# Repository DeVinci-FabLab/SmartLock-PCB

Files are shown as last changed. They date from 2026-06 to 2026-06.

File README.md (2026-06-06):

# SmartLock-PCB

\# SmartLock-PCB

PCB design for the SmartLock project — an electronically controlled lock system developed at the DeVinci FabLab.

Designed with \*\*KiCad\*\*.

\---

\## Project Structure

SmartLock-PCB/

├── SmartLock.kicad\_pro       # KiCad project file

├── SmartLock.kicad\_sch       # Schematic

├── SmartLock.kicad\_pcb       # PCB layout

├── gerbers/                  # Fabrication files (Gerber + drill)

├── bom/                      # Bill of Materials

└── README.md

\## Description

This board handles the control logic for the SmartLock system. It interfaces with:

\- An electronic locking mechanism (solenoid / servo)

\- An access control module (badge reader / keypad / BLE)

\- A microcontroller for logic and communication

>  This section should be updated with the actual components once the schematic is finalized.

\---

\## How to Open the Project

1\. Install \[KiCad](https://www.kicad.org/) (version 7 or later recommended)

2\. Clone this repository:

```

&#x20;  git clone https://github.com/DeVinci-FabLab/SmartLock-PCB.git

```

3\. Open `SmartLock.kicad\_pro` in KiCad

\---

\## Ordering the PCB

Gerber files for fabrication are located in the `gerbers/` folder.  

They can be sent directly to a PCB manufacturer (JLCPCB, PCBWay, etc.).

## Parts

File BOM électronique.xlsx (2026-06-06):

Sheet: Feuil1
Numéro d'article | Article | Type/Catégorie | Quantité | Fournisseur | Coût Unitaire | Coût Total Estimé | Lien
1 | Rasp 0 12W (Raspberry Pi) | Micro-ordinateur U10 | 3 | Kubii | 18.00 € | 54.00 € | https://www.kubii.com/fr/cartes-nano-ordinateurs/3455-raspberry-pi-zero-2-w.html?src=raspberrypi
2 | BIGTREETECH SKSM V1.0 | Carte sauveuse de donnée J2 | 3 | Biqu | 16.25 € | 48.75 € | https://biqu.equipment/products/bigtreetech-sksm-v1-0
3 | PN532 | Lecteur RFID/NFC U20 | 3 | robotshop | 5.94 € | 17.82 € | https://eu.robotshop.com/products/elecrow-pn532-nfc-module-pn532-rfid-v3-module
4 | 7inch Capacitive Touch Screen LCD (H), 1024×600, HDMI, IPS, Various Systems Support | Écran / IHM | 3 | Gotronic | 47.99 € | 143.97 € | https://www.waveshare.com/7inch-hdmi-lcd-h.htm
5 | Capteur a effet hall | Capteur magnétique U15 | 3 | RS | 2.05 € | 6.15 € | https://fr.rs-online.com/web/p/capteurs-a-effet-hall/1811441
6 | Led rouge | Composants elec D20, D21 | 6 | Gotronic | 0.90 € | 5.40 € | https://www.gotronic.fr/art-led-5-mm-l56bhd-2104.htm
7 | Buzzer | Composants elec BZ2 | 3 | Gotronic | 3.60 € | 10.80 € | https://www.gotronic.fr/art-buzzer-sv4-3830.htm
8 | Samsung 25R 18650 | Batterie de secours BT4, BT5, BT6 | 9 | Taklope | 4.30 € | 38.70 € | https://www.taklope.com/samsung/2240-samsung-inr-25r-18650-2500-mah.html
9 | Régulateur CC-CC MC34063ADR | Step-up / Step-down U1-U4 | 25 | RS | 0.57 € | 14.27 € | https://fr.rs-online.com/web/p/convertisseurs-dc-dc/2184547
10 | Interupteur | Protection de circuit SW1 | 3 | RS | 4.50 € | 13.50 € | https://fr.rs-online.com/web/p/interrupteurs-a-bascule/1858229
11 | Solénoïde | Verrou L10 | 3 | JZIK (sinon amazon) | 7.76 € | 23.28 € | https://www.jzk-jzk.com/fr/products/dc-12v-electric-solenoid-lock-assembly-security-lock-for-security-system-safes-door-cabinet
12 | Porte-fusible PF14 | Protection de circuit | 3 | Gotronic | 0.25 € | 0.75 € | https://www.gotronic.fr/art-porte-fusible-pf14-5553.htm
13 | Fusible temporisé 3,15 A | Protection de circuit F1 | 6 | Gotronic | 0.25 € | 1.50 € | https://www.gotronic.fr/art-fusible-temporise-3-15-a-5485.htm
14 | Diode 1N5822 | D1-D4, D10, D11 | 20 | Gotronic | 0.50 € | 10.00 € | https://www.gotronic.fr/art-1n5822-105.htm
15 | Adaptateur AC/DC 220V-12V | Alimentation secteur J8 | 3 | RS | 25.98 € | 77.94 € | https://fr.rs-online.com/web/p/adaptateurs-ac-dc/1753327
16 | Connecteur Aviateur | Connectique J3, J9 | 3 | Audiophonics | 1.90 € | 5.70 € | https://www.audiophonics.fr/en/plane-type-plugs/gx12-connector-2-poles-300v-5a-o5mm-p-9979.html
17 | Mosfet | Connectique Q1 | 3 | RS | 1.28 € | 3.84 € | https://fr.rs-online.com/web/p/transistors-mosfet/5410086 | Total 3 armoires | 544.76 €
18 | Cable Hdmi - mini Hdmi | Câblage | 3 | RS | 10.25 € | 30.75 € | https://fr.rs-online.com/web/p/cables-hdmi/1828892 | Total 1 armoire | 181.59 €
19 | BMS 3S | Gestion batterie J10 | 3 | Otronic | 2.05 € | 6.15 € | https://www.otronic.nl/fr/circuit-de-protection-bms-3s-avec-fonction-dequili.html
20 | Cable Usb - Micro Usb | Câblage | 3 | Gotronic | 3.90 € | 11.70 € | https://www.gotronic.fr/art-cordon-micro-usb-32141.htm
21 | Inductance 100µH | L1, L2, L3 | 3 | Gotronic | 0.60 € | 1.80 € | https://www.gotronic.fr/art-self-miniature-100-uh-3521.htm
22 | Inductance 150µH | L4 | 1 | Switch eletronics | 1.78 € | 1.78 € | https://www.switchelectronics.co.uk/products/150%C2%B5h-10-radial-inductor-22r154c
23 | R 13 kΩ | R32 | 5 | e44 | 0.10 € | 0.50 € | https://www.e44.com/composants/composants-passifs/resistances/resistances-precision/0-25-w/resistance-couche-metallique-1-4w-13-kohms-1-MA13K0.html
24 | R 1.5 Ω | R_SC4 | 1 | Gotronic | 0.15 € | 0.15 € | https://www.gotronic.fr/art-10-resistances-1-4w-1-5-8486-2545.htm
25 | R 3.6 kΩ | R12, R22 | 2 | RS | 4.28 € | 8.56 € | https://ma.rsdelivers.com/product/vishay/mrs25000c3601fct00/resistance-film-couche-mince-36k%CF%89-1-06w/6834219P
26 | R 9.1 kΩ | R42 | 1 | Gotronic | 0.25 € | 0.25 € | https://www.gotronic.fr/art-5-resistances-1-2w-9-1-k-8486-8835.htm
27 | R 1.0 kΩ | R41 | 1 | Gotronic | 0.15 € | 0.15 € | https://www.gotronic.fr/art-10-resistances-1-4w-1-0k-8486-2574.htm
28 | R 1.2 kΩ | R11, R21 | 1 | Gotronic | 0.15 € | 0.15 € | https://www.gotronic.fr/art-10-resistances-1-4w-1-2k-8486-2575.htm
29 | R 0.33 Ω | R_SC1, R_SC2 | 2 | Gotronic | 0.55 € | 1.10 € | https://www.gotronic.fr/art-resistance-bobinee-5w-0-33-8486-2813.htm
30 | R 0.47 Ω | R_SC3 | 2 | Gotronic | 0.55 € | 1.10 € | https://www.gotronic.fr/art-resistance-bobinee-5w-0-47-8486-2815.htm
31 | R 1.5 kΩ | R31 | 1 | Gotronic | 0.15 € | 0.15 € | https://www.gotronic.fr/art-10-resistances-1-4w-1-5k-8486-2576.htm
32 | C 560 pF | C_T1 | 1 | Gotronic | 0.10 € | 0.10 € | https://www.gotronic.fr/art-condensateur-ceramique-560-pf-3195.htm
33 | C 100µF/50V | C1, C_O1, C2, C3, C_O3, C4, C_O4 | 15 | Gotronic | 0.20 € | 3.00 € | https://www.gotronic.fr/art-condensateur-radial-100uf-50v-229.htm
34 | C 680 pF | C_T2 | 1 | Gotronic | 0.10 € | 0.10 € | https://www.gotronic.fr/art-condensateur-ceramique-680-pf-3196.htm
35 | C 220 µF / 50V | C_O2 | 5 | Gotronic | 0.10 € | 0.50 € | https://www.gotronic.fr/art-condensateur-radial-220uf-50v-3381.htm
36 | C 150 pF | C_T3 | 1 | Gotronic | 0.10 € | 0.10 € | https://www.gotronic.fr/art-condensateur-ceramique-150-pf-3188.htm
37 | C 120 pF | C_T4 | 1 | Gotronic | 0.10 € | 0.10 € | https://www.gotronic.fr/art-condensateur-ceramique-120-pf-3187.htm
38 | R 330 Ω | R1, R2, R3, R4 | 1 | Gotronic | 0.20 € | 0.20 € | https://www.gotronic.fr/art-10-resistances-1-4w-330-8486-2570.htm
 |  |  |  |  |  | 0.00 €
 | R 1.5 kΩ | R11
 | R 4,7 kΩ | R12
 | R 0.15 Ω | R_SC1

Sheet: Feuil2
Régulateur 12V-5V (page 9) |  |  |  |  | Condensateurs |  |  | Résistances |  |  | Inductances |  |  | Diodes
Composant | Valeur Calculée | Valeur Suggérée (E12/E24) |  |  | 560.00 | pF (céramique) | 2 | 0.33 | Ω | 3 | 100 | µH | 4 | 1N5819 | Schottky
CT (C1) | 564 pF | 560 pF (Céramique) |  | 8 | 100 | µF (chimique 15-25V) | 2 | 1200 | Ω |  | 150 | µH
Rsc (R3) | 0,3 Ω | 0,33 Ω (1/2W) |  |  | 680 | pF | 2 | 3600 | Ω
L (L1) | 87,4μH | 100μH (Courant >1,2 A) |  |  | 220 | µF |  | 1500 | Ω
Co (C2) | 75μF | 100μF (Chimique, 16V ou 25V) |  |  | 150 | pF |  | 13000 | Ω
R1 | 1,2 kΩ | 1,2 kΩ |  |  | 120 | pF |  | 0.47 | Ω
R2 | 3,6 kΩ | 3,6 kΩ |  |  |  |  |  | 1000 | Ω
D1 | Diode Schottky | 1N5819 |  |  |  |  |  | 9100 | Ω
 |  |  |  |  |  |  |  | 1.5 | Ω
Régulateur 11,1V-5V (page 10)
Composant | Valeur Calculée | Valeur Standard (Marché) | Rôle
R1 | 1.2kΩ | 1.2kΩ | Pont diviseur
R2 | 3.6kΩ | 3.6kΩ | Fixe la tension à 5.0V
Rsc | 0.3Ω | 0.33Ω (1W) | Limite le courant pic (~0.9A)
Ct | 620pF | 680pF | Condensateur de timing
L1 | 78μH | 100μH | Inductance (Courant > 1A)
Co | 110μF | 220μF | Condensateur sortie (Low ESR)
D1 | Schottky | 1N5819 | Diode de roue libre
Régulateur 11,1V-12V (page 11)
Composant | Valeur Calculée | Valeur Standard (Marché) | Rôle
R1 | 1.5kΩ | 1.5kΩ | Pont diviseur
R2 | 12.9kΩ | 13kΩ | Fixe la tension à ~12.08V
Ct | 140pF | 150pF | Critique : Valeur très faible due au rapport cyclique court.
L1 | 82μH | 100μH | Inductance (Courant > 0.5A)
Rsc | 0.66Ω | 0.47Ω ou 0.5Ω | Limite de courant (~0.6A pic)
Co | 10μF (min) | 100μF | Électrolytique (25V)
D1 | Schottky | 1N5819 | Diode rapide
Régulateur 12V-12,6V (page 12)
Composant | Valeur Calculée | Valeur Standard Recommandée | Note Technique
R1 | 1kΩ | 1kΩ
R2 | 9.08kΩ | 9.1kΩ | Donne Vout≈12.62V
Ct | 120pF | 100pF ou 120pF | Attention : Valeur très faible car le temps d'activation (ton) est court.
L1 | 145μH | 150μH | Pour Iout=100mA
Rsc | 1.36Ω | 1.2Ω ou 1.5Ω | Limite le courant pic (Ipk) à ~250mA pour protéger la charge.
Co | 10μF (min) | 100μF | Électrolytique (Low ESR)

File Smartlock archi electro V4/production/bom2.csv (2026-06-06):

Id | Référence | Empreinte | Quantité | Désignation | Fournisseur et réf
1 | U?,U? | CONN-TH_XH-2A | 2 | CONN-TH_XH-2A
2 | U? | CONN-TH_4P-P2.50_XH-4A | 1 | CONN-TH_4P-P2.50_XH-4A
3 | R31,R32,R22,R21,R12,R11,R3,R2,R1 | R0805 | 9 | R
4 | D3,D12,D11,D10,D4,D2,D1 | SMA_L4.3-W2.6-LS5.2-RD | 7 | 1N5822
5 | U? | CONN-TH_XH-3A | 1 | CONN-TH_XH-3A
6 | R42 | R0402 | 1 | R
7 | C_O4,C_O3,C_O1,C4,C3,C2,C1 | CAP-SMD_BD8.0-L8.3-W8.3-LS9.1-FD | 7 | C_Polarized
8 | U? | CONN-TH_5P-P2.50_XH-5A_C2318 | 1 | CONN-TH_5P-P2.50_XH-5A_C2318
9 | U4 | SOIC-8_L4.9-W3.9-P1.27-LS6.0-BL | 1 | Regulator 12V-12.6V
10 | U3 | SOIC-8_L4.9-W3.9-P1.27-LS6.0-BL | 1 | Regulator 11.1V-12V
11 | U2 | SOIC-8_L4.9-W3.9-P1.27-LS6.0-BL | 1 | Regulator 11.1V-5V
12 | U1 | SOIC-8_L4.9-W3.9-P1.27-LS6.0-BL | 1 | Regulator 12V-5V
13 | R_SC4,R_SC2,R_SC1,R_PD1,R41 | R1206 | 5 | R
14 | R_SC3 | R0603 | 1 | R
15 | R40 | R1206 | 1 | R40
16 | R30 | R1206 | 1 | R30
17 | Q1 | SOT-23-3_L2.9-W1.3-P1.90-LS2.4-BR | 1 | Q_NMOS_GSD
18 | L4 | IND-SMD_L12.3-W12.3 | 1 | L4
19 | L3 | IND-SMD_L12.3-W12.3_SMDRI127 | 1 | L3
20 | L2 | IND-SMD_L12.3-W12.3_SMDRI127 | 1 | L2
21 | L1 | IND-SMD_L12.3-W12.3_SMDRI127 | 1 | L1
22 | C_T4,C_T3,C_T2,C_T1 | C0603 | 4 | C
23 | C_O2 | CAP-SMD_BD10.0-L10.3-W10.3-LS11.3-FD | 1 | C_Polarized

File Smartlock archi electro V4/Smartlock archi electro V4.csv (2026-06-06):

Reference | Qty | Value | DNP | Exclude from BOM | Exclude from Board | Footprint | JLCPCB
BT4 | 1 | Battery
BT5 | 1 | Battery
BT6 | 1 | Battery
BZ2 | 1 | Buzzer
C1 | 1 | C_Polarized |  |  |  | Components_local:CAP-SMD_BD8.0-L8.3-W8.3-LS9.1-FD | https://jlcpcb.com/partdetail/DMBJ-RVT1H101M0810_100UF50V/C970687
C2 | 1 | C_Polarized |  |  |  | Components_local:CAP-SMD_BD8.0-L8.3-W8.3-LS9.1-FD | https://jlcpcb.com/partdetail/DMBJ-RVT1H101M0810_100UF50V/C970687
C3 | 1 | C_Polarized |  |  |  | Components_local:CAP-SMD_BD8.0-L8.3-W8.3-LS9.1-FD | https://jlcpcb.com/partdetail/DMBJ-RVT1H101M0810_100UF50V/C970687
C4 | 1 | C_Polarized |  |  |  | Components_local:CAP-SMD_BD8.0-L8.3-W8.3-LS9.1-FD | https://jlcpcb.com/partdetail/DMBJ-RVT1H101M0810_100UF50V/C970687
C_O1 | 1 | C_Polarized |  |  |  | Components_local:CAP-SMD_BD8.0-L8.3-W8.3-LS9.1-FD | https://jlcpcb.com/partdetail/DMBJ-RVT1H101M0810_100UF50V/C970687
C_O2 | 1 | C_Polarized |  |  |  | Components_local:CAP-SMD_BD10.0-L10.3-W10.3-LS11.3-FD | https://jlcpcb.com/partdetail/DMBJ-RVT1H221M1010_220UF50V/C970698
C_O3 | 1 | C_Polarized |  |  |  | Components_local:CAP-SMD_BD8.0-L8.3-W8.3-LS9.1-FD | https://jlcpcb.com/partdetail/DMBJ-RVT1H101M0810_100UF50V/C970687
C_O4 | 1 | C_Polarized |  |  |  | Components_local:CAP-SMD_BD8.0-L8.3-W8.3-LS9.1-FD | https://jlcpcb.com/partdetail/DMBJ-RVT1H101M0810_100UF50V/C970687
C_T1 | 1 | C |  |  |  | Components_local:C0603 | https://jlcpcb.com/partdetail/1979-0603B561K500NT/C1627
C_T2 | 1 | C |  |  |  | Components_local:C0603 | https://jlcpcb.com/partdetail/1982-0603B681K500NT/C1630
C_T3 | 1 | C |  |  |  | Components_local:C0603 | https://jlcpcb.com/partdetail/1946-0603B151K500NT/C1594
C_T4 | 1 | C |  |  |  | Components_local:C0603 | https://jlcpcb.com/partdetail/1995-0603CG121J500NT/C1643
D1 | 1 | 1N5822 |  |  |  | Components_local:SMA_L4.3-W2.6-LS5.2-RD | https://jlcpcb.com/partdetail/MDD_Microdiode_Semiconductor-SS34/C8678
D2 | 1 | 1N5822 |  |  |  | Components_local:SMA_L4.3-W2.6-LS5.2-RD | https://jlcpcb.com/partdetail/MDD_Microdiode_Semiconductor-SS34/C8678
D3 | 1 | 1N5822 |  |  |  | Components_local:SMA_L4.3-W2.6-LS5.2-RD | https://jlcpcb.com/partdetail/MDD_Microdiode_Semiconductor-SS34/C8678
D4 | 1 | 1N5822 |  |  |  | Components_local:SMA_L4.3-W2.6-LS5.2-RD | https://jlcpcb.com/partdetail/MDD_Microdiode_Semiconductor-SS34/C8678
D10 | 1 | 1N5822 |  |  |  | Components_local:SMA_L4.3-W2.6-LS5.2-RD | https://jlcpcb.com/partdetail/MDD_Microdiode_Semiconductor-SS34/C8678
D11 | 1 | 1N5822 |  |  |  | Components_local:SMA_L4.3-W2.6-LS5.2-RD | https://jlcpcb.com/partdetail/MDD_Microdiode_Semiconductor-SS34/C8678
D12 | 1 | 1N5822 |  |  |  | Components_local:SMA_L4.3-W2.6-LS5.2-RD | https://jlcpcb.com/partdetail/MDD_Microdiode_Semiconductor-SS34/C8678
D20 | 1 | LED
D21 | 1 | LED
F1 | 1 | Fuse
J1 | 1 | HDMI_A
J2 | 1 | SKSM V1.0
J3 | 1 | Conn_aviateur in
J4 | 1 | HDMI_C_1.3
J5 | 1 | USB_OTG
J6 | 1 | USB_A
J7 | 1 | USB_OTG
J8 | 1 | Adaptateur 220V-12V
J9 | 1 | Conn_aviateur out
J10 | 1 | BMS_3S
L1 | 1 | L1 |  |  |  | Components_local:IND-SMD_L12.3-W12.3_SMDRI127 | https://jlcpcb.com/partdetail/10690-SMDRI127101MT/C10150
L2 | 1 | L2 |  |  |  | Components_local:IND-SMD_L12.3-W12.3_SMDRI127 | https://jlcpcb.com/partdetail/10690-SMDRI127101MT/C10150
L3 | 1 | L3 |  |  |  | Components_local:IND-SMD_L12.3-W12.3_SMDRI127 | https://jlcpcb.com/partdetail/10690-SMDRI127101MT/C10150
L4 | 1 | L4 |  |  |  | Components_local:IND-SMD_L12.3-W12.3 | https://jlcpcb.com/partdetail/22042-SMDRI127151MT/C21325
L10 | 1 | Solénoïde
Q1 | 1 | Q_NMOS_GSD |  |  |  | Components_local:SOT-23-3_L2.9-W1.3-P1.90-LS2.4-BR | https://jlcpcb.com/partdetail/Alpha_OmegaSemicon-AO3400A/C20917
R1 | 1 | R |  |  |  | Components_local:R0805 | https://jlcpcb.com/partdetail/18318-0805W8F3300T5E/C17630
R2 | 1 | R |  |  |  | Components_local:R0805 | https://jlcpcb.com/partdetail/18318-0805W8F3300T5E/C17630
R3 | 1 | R |  |  |  | Components_local:R0805 | https://jlcpcb.com/partdetail/18318-0805W8F3300T5E/C17630
R4 | 1 | R |  |  |  | Components_local:R0805
R11 | 1 | R |  |  |  | Components_local:R0805 | https://jlcpcb.com/partdetail/18067-0805W8F1201T5E/C17379
R12 | 1 | R |  |  |  | Components_local:R0805 | https://jlcpcb.com/partdetail/1717-0805W8J0362T5E/C1365
R21 | 1 | R |  |  |  | Components_local:R0805 | https://jlcpcb.com/partdetail/18067-0805W8F1201T5E/C17379
R22 | 1 | R |  |  |  | Components_local:R0805 | https://jlcpcb.com/partdetail/1717-0805W8J0362T5E/C1365
R30 | 1 | R30 |  |  |  | Components_local:R1206 | https://jlcpcb.com/partdetail/18612-1206W4F1800T5E/C17924
R31 | 1 | R |  |  |  | Components_local:R0805 | https://jlcpcb.com/partdetail/4717-0805W8F1501T5E/C4310
R32 | 1 | R |  |  |  | Components_local:R0805 | https://jlcpcb.com/partdetail/18143-0805W8F1302T5E/C17455
R40 | 1 | R40 |  |  |  | Components_local:R1206 | https://jlcpcb.com/partdetail/18612-1206W4F1800T5E/C17924
R41 | 1 | R |  |  |  | Components_local:R1206 | https://jlcpcb.com/partdetail/1821-1206W4J0102T5E/C1469
R42 | 1 | R |  |  |  | Capacitor_SMD_local:R0603 | https://jlcpcb.com/partdetail/VikingTech-ARG03BTC8761N/C2684583
R_PD1 | 1 | R |  |  |  | Components_local:R1206 | https://jlcpcb.com/partdetail/1841-1206W4J0103T5E/C1489
R_SC1 | 1 | R |  |  |  | Components_local:R1206 | https://jlcpcb.com/partdetail/26080-1206W4F330LT5E/C25337
R_SC2 | 1 | R |  |  |  | Components_local:R1206 | https://jlcpcb.com/partdetail/26080-1206W4F330LT5E/C25337
R_SC3 | 1 | R |  |  |  | Components_local:R0603 | https://jlcpcb.com/partdetail/24144-0603WAF470LT5E/C23411
R_SC4 | 1 | R |  |  |  | Components_local:R1206 | https://jlcpcb.com/partdetail/18587-1206W4F150KT5E/C17899
SW1 | 1 | Interupteur
U1 | 1 | Regulator 12V-5V |  |  |  | Components_local:SOIC-8_L4.9-W3.9-P1.27-LS6.0-BL | https://jlcpcb.com/partdetail/TexasInstruments-MC34063ADR/C100023
U2 | 1 | Regulator 11.1V-5V |  |  |  | Components_local:SOIC-8_L4.9-W3.9-P1.27-LS6.0-BL | https://jlcpcb.com/partdetail/TexasInstruments-MC34063ADR/C100023
U3 | 1 | Regulator 11.1V-12V |  |  |  | Components_local:SOIC-8_L4.9-W3.9-P1.27-LS6.0-BL | https://jlcpcb.com/partdetail/TexasInstruments-MC34063ADR/C100023
U4 | 1 | Regulator 12V-12.6V |  |  |  | Components_local:SOIC-8_L4.9-W3.9-P1.27-LS6.0-BL | https://jlcpcb.com/partdetail/TexasInstruments-MC34063ADR/C100023
U5 | 1 | LTV-817 |  |  |  | Components_local:OPTO-SMD-4_L4.6-W6.5-P2.54-LS10.3-BL | https://jlcpcb.com/parts/componentSearch?searchTxt=817%20SOP-4
U10 | 1 | RASPBERRY_PI_ZERO_2_W
U15 | 1 | Capteur magnetic
U20 | 1 | PN532

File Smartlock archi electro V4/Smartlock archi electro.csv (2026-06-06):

Reference | Qty | Value | DNP | Exclude from BOM | Exclude from Board | Footprint | JLCPCB
BT4,BT5,BT6 | 3 | Battery
BZ2 | 1 | Buzzer
C1,C2,C3,C4 | 4 | C_Polarized |  |  |  | Components_local:CAP-SMD_BD8.0-L8.3-W8.3-LS9.1-FD | https://jlcpcb.com/partdetail/DMBJ-RVT1H101M0810_100UF50V/C970687,https://jlcpcb.com/partdetail/DMBJ-RVT1H101M0810_100UF50V/C970687
C_O1,C_O3,C_O4 | 3 | C_Polarized |  |  |  | Components_local:CAP-SMD_BD8.0-L8.3-W8.3-LS9.1-FD | https://jlcpcb.com/partdetail/DMBJ-RVT1H101M0810_100UF50V/C970687
C_O2 | 1 | C_Polarized |  |  |  | Components_local:CAP-SMD_BD10.0-L10.3-W10.3-LS11.3-FD | https://jlcpcb.com/partdetail/DMBJ-RVT1H221M1010_220UF50V/C970698
C_T1,C_T2,C_T3,C_T4 | 4 | C |  |  |  | Components_local:C0603 | https://jlcpcb.com/partdetail/1946-0603B151K500NT/C1594,https://jlcpcb.com/partdetail/1979-0603B561K500NT/C1627 ,https://jlcpcb.com/partdetail/1982-0603B681K500NT/C1630 ,https://jlcpcb.com/partdetail/1995-0603CG121J500NT/C1643
D1,D2,D3,D4,D10,D11,D12 | 7 | 1N5822 |  |  |  | Components_local:SMA_L4.3-W2.6-LS5.2-RD | https://jlcpcb.com/partdetail/MDD_Microdiode_Semiconductor-SS34/C8678
D20,D21 | 2 | LED
F1 | 1 | Fuse
J1 | 1 | HDMI_A
J2 | 1 | SKSM V1.0
J3 | 1 | Conn_aviateur in
J4 | 1 | HDMI_C_1.3
J5,J7 | 2 | USB_OTG
J6 | 1 | USB_A
J8 | 1 | Adaptateur 220V-12V
J9 | 1 | Conn_aviateur out
J10 | 1 | BMS_3S
L1 | 1 | L1 |  |  |  | Components_local:IND-SMD_L12.3-W12.3_SMDRI127 | https://jlcpcb.com/partdetail/10690-SMDRI127101MT/C10150
L2 | 1 | L2 |  |  |  | Components_local:IND-SMD_L12.3-W12.3_SMDRI127 | https://jlcpcb.com/partdetail/10690-SMDRI127101MT/C10150
L3 | 1 | L3 |  |  |  | Components_local:IND-SMD_L12.3-W12.3_SMDRI127 | https://jlcpcb.com/partdetail/10690-SMDRI127101MT/C10150
L4 | 1 | L4 |  |  |  | Components_local:IND-SMD_L12.3-W12.3 | https://jlcpcb.com/partdetail/22042-SMDRI127151MT/C21325
L10 | 1 | Solénoïde
Q1 | 1 | Q_NMOS_GSD |  |  |  | Components_local:SOT-23-3_L2.9-W1.3-P1.90-LS2.4-BR | https://jlcpcb.com/partdetail/Alpha_OmegaSemicon-AO3400A/C20917
R1,R2,R3,R11,R12,R21,R22,R31,R32 | 9 | R |  |  |  | Components_local:R0805 | https://jlcpcb.com/partdetail/1717-0805W8J0362T5E/C1365 ,https://jlcpcb.com/partdetail/18067-0805W8F1201T5E/C17379 ,https://jlcpcb.com/partdetail/18143-0805W8F1302T5E/C17455 ,https://jlcpcb.com/partdetail/18318-0805W8F3300T5E/C17630 ,https://jlcpcb.com/partdetail/4717-0805W8F1501T5E/C4310
R30 | 1 | R30 |  |  |  | Components_local:R1206 | https://jlcpcb.com/partdetail/18612-1206W4F1800T5E/C17924
R40 | 1 | R40 |  |  |  | Components_local:R1206 | https://jlcpcb.com/partdetail/18612-1206W4F1800T5E/C17924
R41 | 1 | R |  |  |  | Components_local:R1206 | https://jlcpcb.com/partdetail/1821-1206W4J0102T5E/C1469
R42 | 1 | R |  |  |  | Components_local:R0402 | https://jlcpcb.com/partdetail/RALEC-RTT029101FTH/C4968
R_PD1 | 1 | R |  |  |  | Components_local:R1206 | https://jlcpcb.com/partdetail/1841-1206W4J0103T5E/C1489
R_SC1,R_SC2,R_SC4 | 3 | R |  |  |  | Components_local:R1206 | https://jlcpcb.com/partdetail/18587-1206W4F150KT5E/C17899 ,https://jlcpcb.com/partdetail/26080-1206W4F330LT5E/C25337
R_SC3 | 1 | R |  |  |  | Components_local:R0603 | https://jlcpcb.com/partdetail/24144-0603WAF470LT5E/C23411
SW1 | 1 | Interupteur
U1 | 1 | Regulator 12V-5V |  |  |  | Components_local:SOIC-8_L4.9-W3.9-P1.27-LS6.0-BL | https://jlcpcb.com/partdetail/TexasInstruments-MC34063ADR/C100023
U2 | 1 | Regulator 11.1V-5V |  |  |  | Components_local:SOIC-8_L4.9-W3.9-P1.27-LS6.0-BL | https://jlcpcb.com/partdetail/TexasInstruments-MC34063ADR/C100023
U3 | 1 | Regulator 11.1V-12V |  |  |  | Components_local:SOIC-8_L4.9-W3.9-P1.27-LS6.0-BL | https://jlcpcb.com/partdetail/TexasInstruments-MC34063ADR/C100023
U4 | 1 | Regulator 12V-12.6V |  |  |  | Components_local:SOIC-8_L4.9-W3.9-P1.27-LS6.0-BL | https://jlcpcb.com/partdetail/TexasInstruments-MC34063ADR/C100023
U10 | 1 | RASPBERRY_PI_ZERO_2_W
U15 | 1 | Capteur magnetic
U20 | 1 | PN532

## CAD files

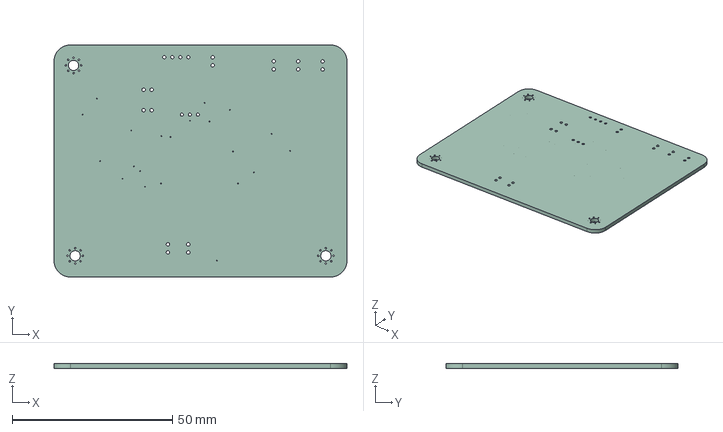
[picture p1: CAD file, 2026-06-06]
Smartlock archi electro V4/Smartlock archi electro V4.step
91.4 x 72.4 x 1.51 mm

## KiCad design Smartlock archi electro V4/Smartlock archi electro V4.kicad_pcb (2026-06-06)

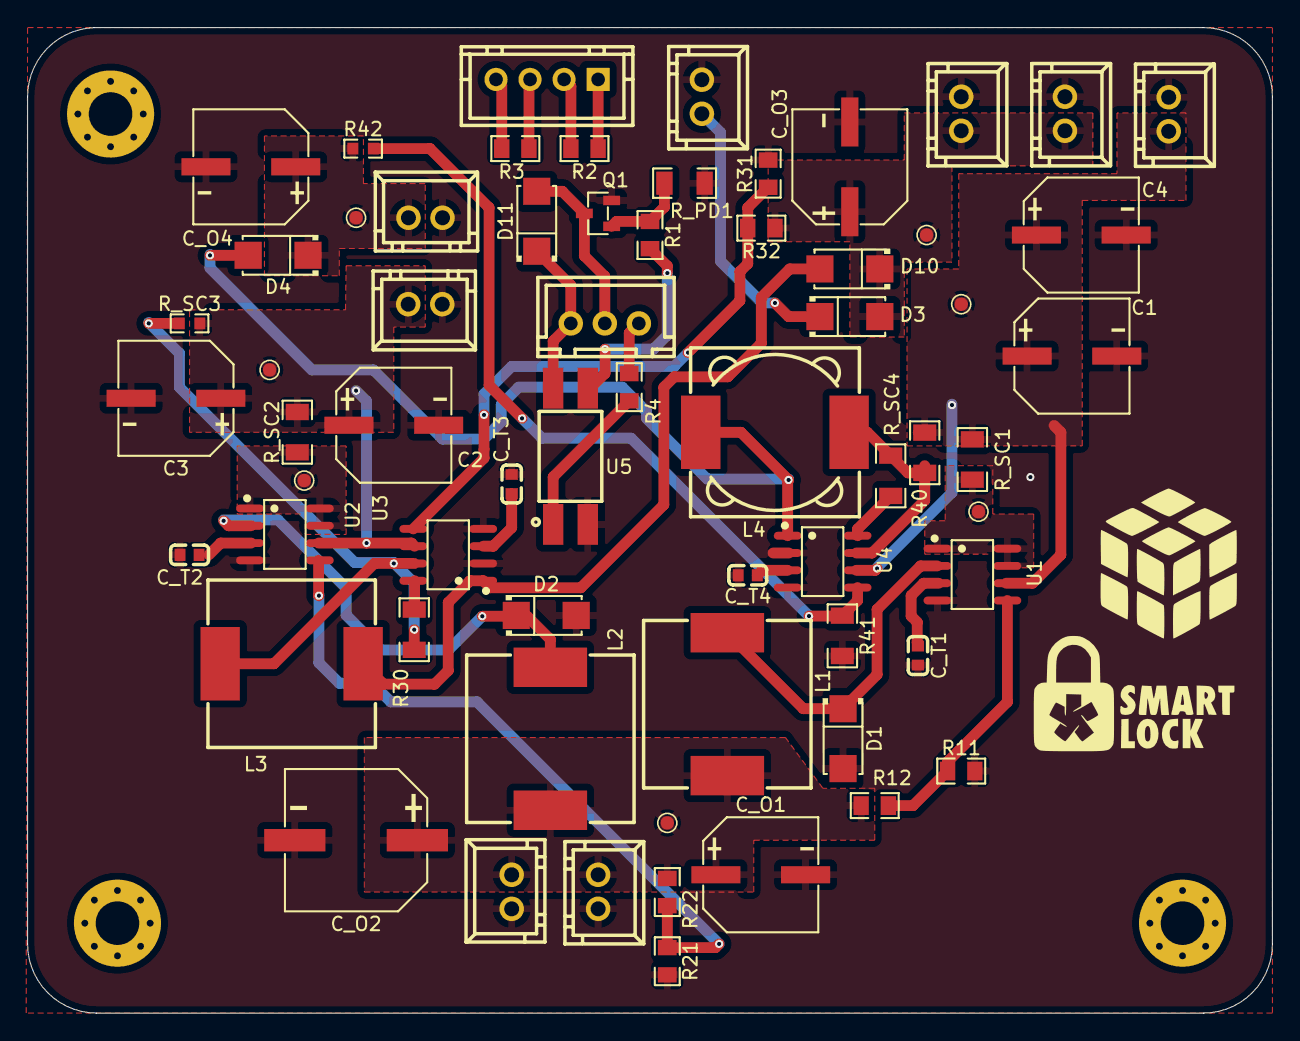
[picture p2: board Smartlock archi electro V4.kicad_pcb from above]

Board: 2 copper layers, 91.4 x 72.4 mm, 57 parts (0 on the bottom side), 35 nets.

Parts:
C1, C2, C3, C4: C_Polarized; CAP-SMD_BD8.0-L8.3-W8.3-LS9.1-FD
C_O1, C_O3, C_O4: C_Polarized; CAP-SMD_BD8.0-L8.3-W8.3-LS9.1-FD
C_O2: C_Polarized; CAP-SMD_BD10.0-L10.3-W10.3-LS11.3-FD
C_T1, C_T2, C_T3, C_T4: C; C0603
D1, D2, D3, D4, D10, D11: 1N5822; SMA_L4.3-W2.6-LS5.2-RD
L1: L1; IND-SMD_L12.3-W12.3_SMDRI127
L2: L2; IND-SMD_L12.3-W12.3_SMDRI127
L3: L3; IND-SMD_L12.3-W12.3_SMDRI127
L4: L4; IND-SMD_L12.3-W12.3
Q1: Q_NMOS_GSD; SOT-23-3_L2.9-W1.3-P1.90-LS2.4-BR
R1, R2, R3, R4, R11, R12, R21, R22, R31, R32: R; R0805
R30: R30; R1206
R40: R40; R1206
R41: R; R1206
R42: R; R0603
R_PD1: R; R1206
R_SC1, R_SC2, R_SC4: R; R1206
R_SC3: R; R0603
U1: Regulator 12V-5V; SOIC-8_L4.9-W3.9-P1.27-LS6.0-BL
U2: Regulator 11.1V-5V; SOIC-8_L4.9-W3.9-P1.27-LS6.0-BL
U3: Regulator 11.1V-12V; SOIC-8_L4.9-W3.9-P1.27-LS6.0-BL
U4: Regulator 12V-12.6V; SOIC-8_L4.9-W3.9-P1.27-LS6.0-BL
U5: LTV-817; OPTO-SMD-4_L4.6-W6.5-P2.54-LS10.3-BL
U?: CONN-TH_XH-2A
U?#2, U?#3, U?#4, U?#5, U?#6, U?#7, U?#10: CONN-TH_XH-2A
U?#8: CONN-TH_4P-P2.50_XH-4A
U?#9: CONN-TH_XH-3A

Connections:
/Carte_puissance/Regulateur 1 12V-5V/Net-(U1-DC): R_SC1.1, U1.1 (SwC), U1.7 (Ipk), U1.8 (DC)
/Carte_puissance/V_in 12V: C1.1, C4.1, R_SC1.2, R_SC4.2, U1.6 (Vin), U4.6 (Vin), U?#4.2
/Carte_puissance/V_out 5V: C_O1.1, C_O2.1, L1.2, L2.2, R12.1, R22.1, U?#3.1, U?#5.2
/Carte_puissance/V_out 12V: C_O3.1, D3.1 (K), D10.2 (A), R32.1, U?#7.2, U?#10.2
GND: C1.2, C2.2, C3.2, C4.2, C_O1.2, C_O2.2, C_O3.2, C_O4.2, C_T1.2, C_T2.2, C_T3.2, C_T4.2, D1.2 (A), D2.2 (A), Q1.2 (S), R11.2, R21.2, R31.2, R41.2, R_PD1.2, U1.4 (GND), U2.4 (GND), U3.2 (SwE), U3.4 (GND), U4.2 (SwE), U4.4 (GND), U5.2, U?.1, U?#2.1, U?#3.2, U?#4.1, U?#5.1, U?#6.2, U?#7.1, U?#10.1
unnamed: D1.1 (K), L1.1, U1.2 (SwE)
unnamed: D2.1 (K), L2.1, U2.2 (SwE)
unnamed: D3.2 (A), L3.2, U3.1 (SwC)
unnamed: D4.2 (A), L4.2, U4.1 (SwC)
unnamed: D10.1 (K), U?.2
unnamed: D11.2 (A), Q1.3 (D), U?#9.2
unnamed: D11.1 (K), U5.4, U?#9.1
unnamed: R2.1, U?#8.1
unnamed: R3.1, U?#8.3
unnamed: Q1.1 (G), R1.1, R_PD1.1
unnamed: R1.2, U5.3
unnamed: R4.1, U5.1
unnamed: C_T1.1, U1.3 (TC)
unnamed: R11.1, R12.2, U1.5 (Vfb)
unnamed: R_SC2.1, U2.1 (SwC), U2.7 (Ipk), U2.8 (DC)
unnamed: C_T2.1, U2.3 (TC)
unnamed: R21.1, R22.2, U2.5 (Vfb)
unnamed: R30.2, U3.8 (DC)
unnamed: L3.1, R30.1, R_SC3.1, U3.7 (Ipk)
unnamed: C_T3.1, U3.3 (TC)
unnamed: R31.1, R32.2, U3.5 (Vfb)
unnamed: R40.2, U4.8 (DC)
unnamed: L4.1, R40.1, R_SC4.1, U4.7 (Ipk)
unnamed: C_T4.1, U4.3 (TC)
unnamed: R41.1, R42.2, U4.5 (Vfb)
unnamed: R2.2, U?#8.2
unnamed: R3.2, U?#8.4
unnamed: R4.2, U?#9.3
V11.1: C2.1, C3.1, R_SC2.2, R_SC3.2, U2.6 (Vin), U3.6 (Vin), U?#2.2
V12.6: C_O4.1, D4.1 (K), R42.1, U?#6.1

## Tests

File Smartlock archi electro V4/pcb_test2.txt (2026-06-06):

Mis à jour R de R_PD à R_PD1.
Annotation terminée.
Annotation terminée.
